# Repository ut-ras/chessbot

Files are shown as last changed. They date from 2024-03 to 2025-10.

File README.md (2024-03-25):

# ChessBot: Automated Chessboard

## Overview

ChessBot is an innovative project developed by the IEEE RAS - Demobots team. It is a CNC-inspired automated chessboard designed to enhance the experience of playing chess. Using an actuated electromagnet gantry system, ChessBot can move magnetized chess pieces across the board autonomously, allowing for a seamless game between two players or against a computer-controlled opponent. The project aims to merge the ancient game of chess with modern technology, providing a unique and interactive experience.

## Features

- **Automated Piece Movement**: Moves chess pieces using an electromagnet on a step-driven gantry system, controlled under the board.

- **Magnetized Chess Pieces**: Each piece is magnetized for precise and secure movement. Piece movements are detected via 3D magnetic sensors underneath each square.

- **Player vs. Computer Mode**: Play against an AI with adjustable difficulty settings.

- **Two-Player Online Mode**: Enjoy an enhanced tele-chess experience with automated piece movements that reflect your partner's movements from across the internet using Lichess

## Installation & Setup (WIP)

Make sure you have Python 3.6 or higher installed on your system. You can download it from the [official Python website](https://www.python.org/downloads/).

If on Windows use WSL for now, as the code is not tested on Windows.

1. Clone the repository to your local machine:

```bash
git clone https://github.com/ut-ras/chessbot.git 
```

2. Install the required Python packages:

```bash
cd chessbot
pip install -r requirements.txt
```
3. install stockfish and note what path it is installed to, you will need this for the python script. On Ubuntu or WSL you can do this with the following commands:

```bash
sudo apt-get install stockfish && which stockfish
```
The output of the `which stockfish` command will be the path to the stockfish binary. Copy that path, you will need this for the python script.

4. In the `python/bitboard_with_stockfish.py` file, change the `stockfish_path` variable to the path of the stockfish binary you found in the previous step.

5. Run the Python script:

```bash
python python/bitboard_with_stockfish.py
```

## Software

- [python/bitboard_with_stockfish.py](python/bitboard_with_stockfish.py) - This is the main file that runs the chess engine. It uses the python-chess library to interface with the Stockfish chess engine. The bitboard implementation is a custom implementation that uses 64-bit integers to represent the chessboard. Makes calls to functions in [python/display_output.py](python/display_output.py), animates the board for a 128x64 display, currently only makes the bitmap.

  - Bitboards are 64bit integer representations of the entire chessboard. 8x8 squares = 64 squares, so a digital for each individual square, that digit is 1 when a piece is on the corresponding square and 0 when a piece is absent from the square.
  - So far we arent using any "standard" bitboard implementations, as our situation is a tad unique. Most chess engines that utilize 12 bitboards, one for each piece type, ( [pawn + knight + bishop + rook + queen + king] * 2 teams = 12 piece types).
  - Here is a diagram of how each space on the chessboard is indexed in the bitboard, the number at each square is the digital that is either high or low depending on if a piece is there or not. For example, square `a4` is position `32`

     ``` 
       8 |  0  1  2  3  4  5  6  7
       7 |  8  9 10 11 12 13 14 15
       6 | 16 17 18 19 20 21 22 23
       5 | 24 25 26 27 28 29 30 31
       4 | 32 33 34 35 36 37 38 39
       3 | 40 41 42 43 44 45 46 47
       2 | 48 49 50 51 52 53 54 55
       1 | 56 57 58 59 60 61 62 63
          -------------------------
          a  b  c  d  e  f  g  h
      ```

## TODO
 - Assemble and test chessboard PCB's - each is an individual rank of the board that connect together.
-  Fill this section in with what we have left to do lol

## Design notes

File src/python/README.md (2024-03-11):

# Simple Chess Bitboard Implementation

This code provides a basic implementation of a chess game using a bitboard representation. It features classes for managing both a traditional 2D array-based board (`RealBoard`) and a 64-bit integer representation (`Bitboard`). The goal is to enable chess move input, update the bitboard accordingly, track changes to test for move legality, and interact with the Stockfish chess engine for move suggestions.

## Overview

- **RealBoard**: A class representing a chessboard using a 2D array. Black pieces are lowercase, while white pieces are uppercase. This class tracks the actual state of the game.
- **Bitboard**: Represents the chessboard as a 64-bit integer, where each bit corresponds to a board square, facilitating efficient move generation and board evaluation.
- **StockfishEngine**: A class for interfacing with the Stockfish chess engine, allowing the program to calculate optimal moves based on the current board state.

## Key Concepts

- **Square vs. Position**: In the context of this code, "square" refers to chessboard coordinates (e.g., a1, h8), while "position" refers to the corresponding index (0-63) in the bitboard representation.
- **Board Representation**: For easy reference, the board is indexed as follows:

```

8 |  0  1  2  3  4  5  6  7
7 |  8  9 10 11 12 13 14 15
6 | 16 17 18 19 20 21 22 23
5 | 24 25 26 27 28 29 30 31
4 | 32 33 34 35 36 37 38 39
3 | 40 41 42 43 44 45 46 47
2 | 48 49 50 51 52 53 54 55
1 | 56 57 58 59 60 61 62 63
\-------------------------
a  b  c  d  e  f  g  h

```

## Features

- **Board Initialization and Display**: Both `RealBoard` and `Bitboard` classes can set up a default chess board and print it in a human-readable format.
- **Move Handling**: Functions are provided for converting user input into board moves, updating the board state, and validating moves.
- **Chess Engine Integration**: The `StockfishEngine` class allows the program to communicate with Stockfish, providing move suggestions and evaluations based on the current game state.

## Usage

1. The game initializes the chessboard in both `RealBoard` and `Bitboard` formats.
2. The user is prompted to enter a move in a specific format (e.g., "e2e4").
3. The program validates the move, updates the board state, and then prints the new board configuration.
4. The Stockfish engine suggests a move based on the current board state, which is also executed and displayed.
5. The game loop continues, alternating between user input and engine suggestions.

## Dependencies

- Python 3
- A local installation of the Stockfish chess engine

## Setup

Ensure you have Python 3 installed and the Stockfish engine executable available on your system. Adjust the `path_to_stockfish` variable in the code to point to your Stockfish executable.

## Running the Program

Execute the script from the command line. The game will start, and you'll be prompted to enter moves in the specified format. Follow the on-screen instructions to play against the Stockfish engine.

## Note

This implementation is a simplified demonstration and may not cover all chess rules and scenarios (e.g., en passant, castling, piece promotions).

```

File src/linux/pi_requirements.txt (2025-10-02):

Adafruit-Blinka==8.39.0
adafruit-circuitpython-busdevice==5.2.6
adafruit-circuitpython-connectionmanager==1.0.1
adafruit-circuitpython-neopixel==6.3.11
adafruit-circuitpython-pixelbuf==2.0.4
adafruit-circuitpython-requests==3.2.3
adafruit-circuitpython-typing==1.10.3
Adafruit-PlatformDetect==3.62.0
Adafruit-PureIO==1.1.11
certifi==2024.2.2
charset-normalizer==3.3.2
colorzero==2.0
gpiozero==2.0.1
idna==3.7
paho-mqtt==2.1.0
pigpio==1.78
pyftdi==0.55.0
pyserial==3.5
pyusb==1.2.1
requests==2.31.0
RPi.GPIO==0.7.1
rpi_ws281x==5.0.0
smbus==1.1.post2
smbus2==0.4.3
sysv-ipc==1.1.0
typing_extensions==4.11.0
urllib3==1.26.0
board==1.0
chess==1.10.0
gpiozero==2.0.1
matplotlib==3.8.4
numpy==1.26.4
Pillow==11.1.0
Requests==2.31.0
smbus==1.1.post2

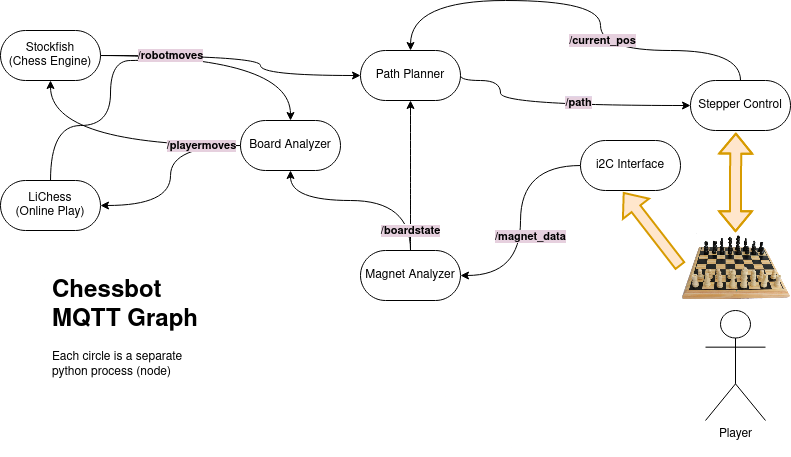
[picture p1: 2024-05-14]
src/display/HighLevelDiagram.drawio.png

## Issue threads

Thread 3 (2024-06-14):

magnetometer @ 0x35 does not work after second init

karmanyaahm, 2024-06-14:
probably some sort of conflict with the default address

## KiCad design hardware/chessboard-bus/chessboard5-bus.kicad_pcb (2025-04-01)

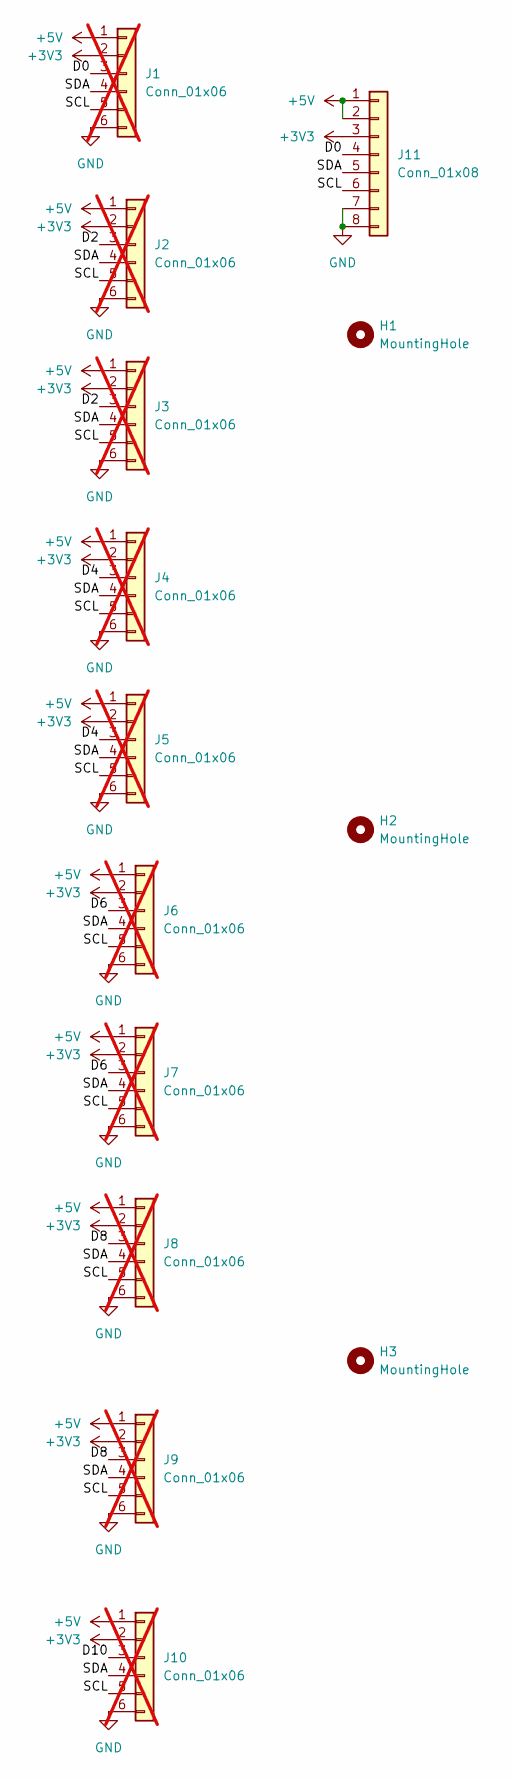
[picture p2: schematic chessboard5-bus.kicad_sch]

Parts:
H1, H2, H3: MountingHole; MountingHole_3.2mm_M3
J1, J2, J3, J4, J5, J6, J7, J8, J9, J10: Conn_01x06; PinHeader_2x03_P2.54mm_Vertical; not fitted
J11: Conn_01x08; JST_PH_S8B-PH-SM4-TB_1x08-1MP_P2.00mm_Horizontal

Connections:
+3V3: J1.2, J2.2, J3.2, J4.2, J5.2, J6.2, J7.2, J8.2, J9.2, J10.2, J11.3
+5V: J1.1, J2.1, J3.1, J4.1, J5.1, J6.1, J7.1, J8.1, J9.1, J10.1, J11.1, J11.2
/D0: J1.3, J11.4
/D2: J2.3, J3.3
/D4: J4.3, J5.3
/D6: J6.3, J7.3
/D8: J8.3, J9.3
/D10: J10.3
/SCL: J1.5, J2.5, J3.5, J4.5, J5.5, J6.5, J7.5, J8.5, J9.5, J10.5, J11.6
/SDA: J1.4, J2.4, J3.4, J4.4, J5.4, J6.4, J7.4, J8.4, J9.4, J10.4, J11.5
GND: J1.6, J2.6, J3.6, J4.6, J5.6, J6.6, J7.6, J8.6, J9.6, J10.6, J11.7, J11.8

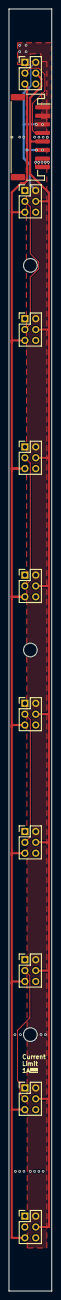
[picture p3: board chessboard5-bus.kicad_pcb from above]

Board: 2 copper layers, 10.0 x 300.0 mm, 14 parts (0 on the bottom side), 10 nets.

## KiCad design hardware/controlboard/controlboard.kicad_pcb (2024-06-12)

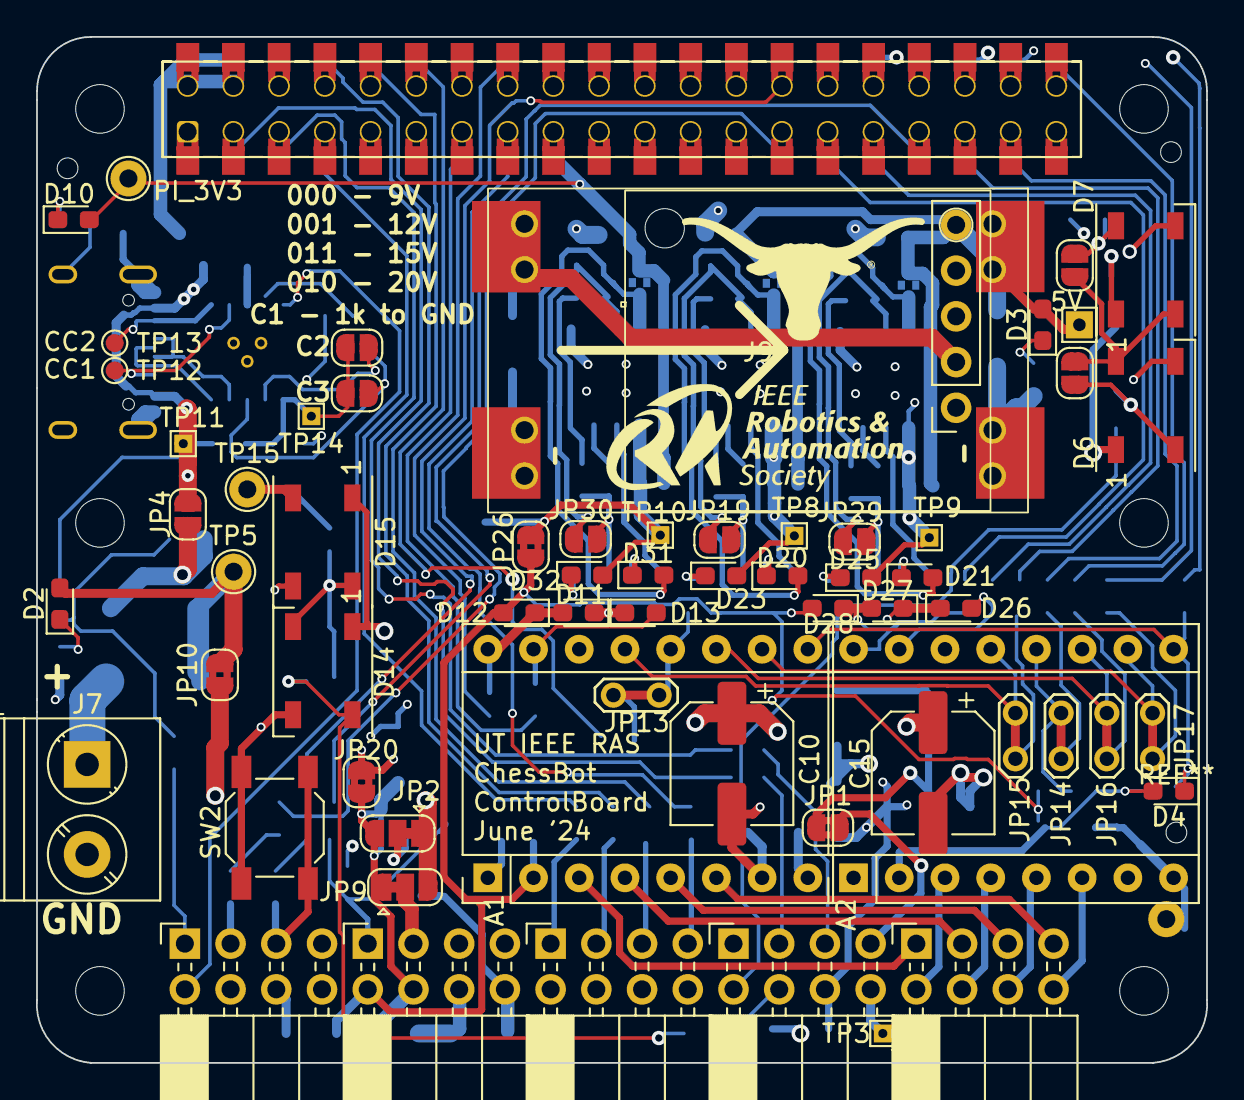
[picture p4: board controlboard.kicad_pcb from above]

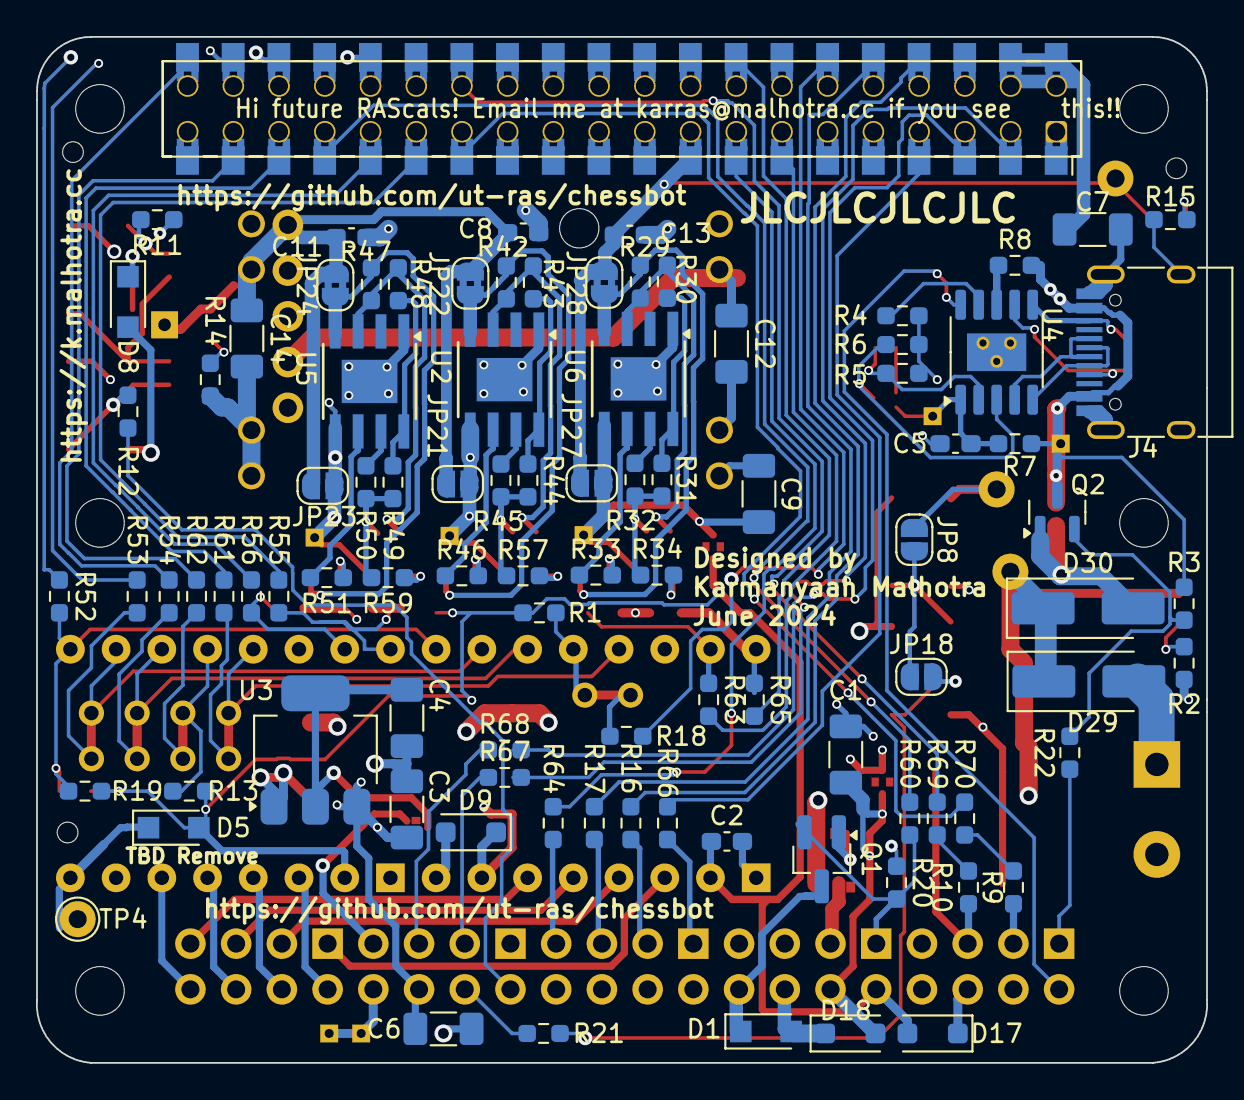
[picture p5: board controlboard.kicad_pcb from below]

Board: 4 copper layers, 65.0 x 57.0 mm, 166 parts (95 on the bottom side), 118 nets.

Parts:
A1: Pololu_Breakout_MP6500; Pololu_Breakout-16_15.2x20.3mm
A2: SilentStepStick TMC5160T; Pololu_Breakout-16_15.2x20.3mm
C1, C3, C4, C6, C7, C9, C12, C14: 22uF; C_1206_3216Metric_Pad1.33x1.80mm_HandSolder
C2, C8, C11, C13: 100n; C_0603_1608Metric_Pad1.08x0.95mm_HandSolder
C5: 1u; C_0603_1608Metric_Pad1.08x0.95mm_HandSolder
C10, C15: 100u; CP_Elec_6.3x5.4
D1, D5, D8: SM4007PL; Nexperia_CFP3_SOD-123W
D2, D3, D4, D10: Y; LED_0603_1608Metric_Pad1.05x0.95mm_HandSolder
D6, D7, D14, D15: WS2812B; LED_WS2812B_PLCC4_5.0x5.0mm_P3.2mm
D9: 20V+ D_TVS; D_SOD-123F
D11, D13, D23, D25, D26, D27, D32: G; LED_0603_1608Metric_Pad1.05x0.95mm_HandSolder
D12, D20, D21, D28, D31: R; LED_0603_1608Metric_Pad1.05x0.95mm_HandSolder
D17: 3V3V+ D_TVS; D_SOD-123F
D18: 6V+ D_TVS; D_SOD-123F
D29, D30: SS54; D_SMA_Handsoldering
J1, J3, J6: Conn_02x04_Counter_Clockwise; PinSocket_2x04_P2.54mm_Horizontal
J2: Conn_02x04_Row_Letter_Last; PinSocket_2x04_P2.54mm_Horizontal
J4: TYPE-C-31-M-12; USB_C_Receptacle_HRO_TYPE-C-31-M-12
J5: Conn_02x04_Row_Letter_First; PinSocket_2x04_P2.54mm_Horizontal
J7: Screw_Terminal_01x02; TerminalBlock_Phoenix_PT-1,5-2-5.0-H_1x02_P5.00mm_Horizontal
J9: mini560 voltage regulator; mini560
J11: Pololu Voltage Regulator; reg15d
J27: GPIO; Samtec_HLE-120-02-xxx-DV-BE-A_2x20_P2.54mm_Horizontal
JP1, JP10, JP20, JP22, JP24, JP26, JP28: SolderJumper_2_Bridged; SolderJumper-2_P1.3mm_Bridged2Bar_RoundedPad1.0x1.5mm
JP2, JP9: SolderJumper_3_Bridged12; SolderJumper-3_P1.3mm_Bridged12_RoundedPad1.0x1.5mm
JP4, JP8, JP11, JP12, JP18, JP19, JP29, JP30: SolderJumper_2_Open; SolderJumper-2_P1.3mm_Open_RoundedPad1.0x1.5mm
JP6, JP7: CFG3; SolderJumper-2_P1.3mm_Open_RoundedPad1.0x1.5mm
JP13, JP14, JP15, JP16, JP17: Jumper_2_Bridged; Bridged_TestPoint_2Pads_Pitch2.54mm_Drill0.8mm
JP21, JP23, JP27: Bypass; SolderJumper-2_P1.3mm_Open_RoundedPad1.0x1.5mm
MH1, MH2, MH3, MH3#2, MH4, MH4#2: MountingHole_2.7mm_M2.5
Q1: NMOS AO3400A; SOT-23_Handsoldering
Q2: PMOS AO3401A; SOT-23
R1, R3, R8, R13, R19, R20, R22, R43, R48: 10k; R_0603_1608Metric_Pad0.98x0.95mm_HandSolder
R2, R4, R5, R6, R7, R9, R10, R11, R12, R14, R15, R16, R17, R18, R21, R34, R52, R55, R56, R57, R59, R60, R62, R63, R64, R65, R66: 1k; R_0603_1608Metric_Pad0.98x0.95mm_HandSolder
R29: 82k; R_0603_1608Metric_Pad0.98x0.95mm_HandSolder
R30: 20k; R_0603_1608Metric_Pad0.98x0.95mm_HandSolder
R31, R44, R49: 47k; R_0603_1608Metric_Pad0.98x0.95mm_HandSolder
R32, R33, R46, R51: 3k; R_0603_1608Metric_Pad0.98x0.95mm_HandSolder
R42, R47: 150k; R_0603_1608Metric_Pad0.98x0.95mm_HandSolder
R45, R50: 470R; R_0603_1608Metric_Pad0.98x0.95mm_HandSolder
R53, R54, R61, R67, R68, R69, R70: 100; R_0603_1608Metric_Pad0.98x0.95mm_HandSolder
SW2: SW_Push TODO FP CHECK; SW_SPST_SKQG_WithStem
TP1, TP3, TP8, TP9, TP10, TP11, TP14: TestPoint; TestPoint_THTPad_1.0x1.0mm_Drill0.5mm
TP4, TP5, TP7, TP15: TestPoint; TestPoint_THTPad_D2.0mm_Drill1.0mm
TP6: TestPoint; TestPoint_THTPad_1.5x1.5mm_Drill0.7mm
TP12, TP13: TestPoint; TestPoint_Pad_D1.0mm
U2, U5, U6: TPS25963x; TI_SO-PowerPAD-8
U3: AMS1117-3.3; SOT-223-3_TabPin2
U4: CH224K; SSOP-10-1EP_3.9x4.9mm_P1mm_EP2.1x3.3mm

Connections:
/CH_5V: C3.1, C6.1, C15.1, D6.1 (VDD), D8.2 (A), D14.1 (VDD), D15.1 (VDD), D23.2 (A), J3.6, J6.4, JP20.2 (B), JP21.1 (A), TP8.1, U2.5 (OUT), U3.3 (VI)
/CH_SCL: J3.5, R68.1
/CH_SDA: J3.3, R67.1
/CNC/(CS/I1)1: A1.12 (I1), JP13.2 (B), R1.2
/CNC/(CS/I1)2: A2.12 (CS), JP14.2 (B), R13.2
/CNC/SCK/MS2: A1.11 (MS2), A2.11 (SCK), JP16.2 (B)
/CNC/SDI/MS1: A1.10 (MS1), A2.10 (SDI), JP17.2 (B)
/CNC/SDO/I2: A1.13 (I2), A2.13 (SDO), JP15.2 (B)
/CNC/SERVO_VIN: C1.1, D18.2 (A2), J5.4, JP2.1 (A), JP9.3 (B), JP20.1 (A)
/CNC/VIO: A1.2 (~FLT), A2.2 (VIO), C2.1, D4.2 (A), D5.2 (A), D12.2 (A), D17.2 (A2), D28.2 (A), J5.2, JP26.1 (A), R1.1, R13.1, R19.1
/CNC/VMOT: A1.8 (VMOT), A2.8 (VMOT), C10.1, D5.1 (K), D9.2 (A2), JP2.3 (B), JP9.1 (A), JP10.1 (A), TP4.1
/ChessBoard/3V3: C4.1, JP1.2 (B), U3.2 (VO)
/ChessBoard/LED_IN: D15.2 (DOUT), JP8.1 (A), TP15.1
/ChessBoard/LED_IN_REAL: D14.4 (DIN), JP18.2 (B), R21.2
/ChessBoard/LED_OUT: J3.2, R12.1
/DIR1: A1.16 (DIR), D11.2 (A), D12.1 (K), R65.1
/DIR2: A2.16 (DIR), D27.2 (A), D28.1 (K), R55.1
/ENBL: A1.9 (~ENABLE), A2.9 (~ENABLE), D4.1 (K), R19.2, R52.2
/ID_SCL: J6.5, R10.2, SW2.1
/ID_SDA: J6.3, R9.1
/LED_DATA: D7.4 (DIN), JP11.2 (B), R11.2
/LIM_SW1: J2.1, R66.1
/LIM_SW2: J2.3, R16.2
/LIM_SW3: J2.5, R17.2
/LIM_SW4: J2.7, R64.1
/MAG_PWM: J5.1, Q1.2 (G), R20.2, R60.1
/MOT_CS1: JP13.1 (A), R18.2
/MOT_CS2: JP14.1 (A), R62.1
/MOT_SCK: JP16.1 (A), R54.2
/MOT_SDI: JP17.1 (A), R53.2
/MOT_SDO: JP15.1 (A), R61.1
/PI_3V3: C13.1, D10.2 (A), J27.17, JP27.2 (B), JP28.2 (B), TP7.1
/PI_5V: C7.1, D25.2 (A), J27.2, J27.4, JP23.1 (A), TP9.1, U5.5 (OUT)
/Power/CH_VDD: C5.1, JP6.1 (A), JP7.1 (A), R7.1, TP14.1, U4.1 (VDD)
/Power/CNC_VIO: C9.1, D32.2 (A), JP26.2 (B), JP27.1 (A), TP10.1, U6.5 (OUT)
/Power/PWR_SW_A: J6.2, U4.10 (PG)
/Power/PWR_SW_B: J6.1, R22.1
/Power/UNLIM_5V: C8.1, C11.1, C14.1, D3.2 (A), J9.1, J11.5, JP21.2 (B), JP22.2 (B), JP23.2 (B), JP24.2 (B), TP6.1
/Power/UNLIM_VIN: C12.1, D2.2 (A), D29.1 (K), D30.1 (K), J6.8, J9.3, J11.2, JP10.2 (B), TP5.1
/Power/VBUS: J4.A4 (VBUS), J4.A9 (VBUS), J4.B4 (VBUS), J4.B9 (VBUS), JP4.1 (A), Q2.3 (S), R3.1, R7.2, R8.2, TP11.1
/STEP1: A1.15 (STEP), D13.2 (A), R63.1
/STEP2: A2.15 (STEP), D26.2 (A), R56.1
GND: A1.1 (GND), A1.7 (GND), A2.1 (GND), A2.7 (GND), C1.2, C2.2, C3.2, C4.2, C5.2, C6.2, C7.2, C8.2, C9.2, C10.2, C11.2, C12.2, C13.2, C14.2, C15.2, D1.2 (A), D6.3 (VSS), D7.3 (VSS), D9.1 (A1), D11.1 (K), D13.1 (K), D14.3 (VSS), D15.3 (VSS), D17.1 (A1), D18.1 (A1), D26.1 (K), D27.1 (K), J2.2, J2.4, J2.6, J2.8, J3.1, J4.A1 (GND), J4.A12 (GND), J4.B1 (GND), J4.B12 (GND), J4.S1 (SHIELD), J5.5, J5.6, J5.7, J6.6, J6.7, J7.2, J9.2, J9.4, J11.3, J11.4, J27.6, J27.9, J27.14, J27.20, J27.25, J27.30, J27.34, J27.39, JP19.1 (A), JP29.1 (A), JP30.1 (A), R2.1, R4.1, R5.1, R6.1, R14.1, R15.1, R20.1, R31.2, R32.2, R34.1, R44.2, R45.2, R49.2, R50.2, R57.1, R59.1, SW2.2, U2.1 (GND), U2.9 (GND), U3.1 (GND), U4.11 (GND), U5.1 (GND), U5.9 (GND), U6.1 (GND), U6.9 (GND)
unnamed: A1.4 (1A), J1.3
unnamed: A1.3 (1B), J1.1
unnamed: A1.5 (2A), J1.5
unnamed: A1.6 (2B), J1.7
unnamed: A2.4 (1A), J1.4
unnamed: A2.3 (1B), J1.2
unnamed: A2.5 (2A), J1.6
unnamed: A2.6 (2B), J1.8
unnamed: D1.1 (K), J5.8, Q1.3 (S)
unnamed: D2.1 (K), R2.2
unnamed: D3.1 (K), R14.2
unnamed: D6.4 (DIN), D7.2 (DOUT), JP11.1 (A), JP12.2 (B)
unnamed: D6.2 (DOUT), JP12.1 (A), R12.2
unnamed: D7.1 (VDD), D8.1 (K)
unnamed: D10.1 (K), R15.2
unnamed: D14.2 (DOUT), D15.4 (DIN), JP8.2 (B), JP18.1 (A)
unnamed: D20.2 (A), JP22.1 (A), R42.1, U2.4 (IN)
unnamed: D20.1 (K), R46.2
unnamed: D21.2 (A), JP24.1 (A), R47.1, U5.4 (IN)
unnamed: D21.1 (K), R51.2
unnamed: D23.1 (K), R57.2
unnamed: D25.1 (K), R59.2
unnamed: D29.2 (A), J7.1
unnamed: D30.2 (A), JP4.2 (B), Q2.1 (D)
unnamed: D31.2 (A), JP28.1 (A), R29.1, U6.4 (IN)
unnamed: D31.1 (K), R33.2
unnamed: D32.1 (K), R34.2
unnamed: J3.4, R21.1
unnamed: J3.7, JP1.1 (A)
unnamed: J3.8, TP1.1, TP3.1
unnamed: J4.A5 (CC1), TP12.1, U4.7 (CC1)
unnamed: J4.B5 (CC2), TP13.1, U4.6 (CC2)
unnamed: J5.3, JP2.2 (C)
unnamed: J27.3, R67.2
unnamed: J27.5, R68.2
unnamed: J27.7, R66.2
unnamed: J27.8, R16.1
unnamed: J27.10, R17.1
unnamed: J27.12, R18.1
unnamed: J27.13, R63.2
unnamed: J27.15, R64.2
unnamed: J27.16, R65.2
unnamed: J27.27, R70.2
unnamed: J27.28, R69.1
unnamed: J27.29, R55.2
unnamed: J27.31, R56.2
unnamed: J27.32, R11.1
unnamed: J27.33, R60.2
unnamed: J27.35, R61.2
unnamed: J27.36, R52.1
unnamed: J27.37, R62.2
unnamed: J27.38, R53.1
unnamed: J27.40, R54.1
unnamed: JP6.2 (B), R5.2, U4.2 (CFG2)
unnamed: JP7.2 (B), R6.2, U4.3 (CFG3)
unnamed: JP9.2 (C), Q1.1 (D)
unnamed: JP19.2 (B), R42.2, R43.1, U2.3 (EN/UVLO)
unnamed: JP29.2 (B), R47.2, R48.1, U5.3 (EN/UVLO)
unnamed: JP30.2 (B), R29.2, R30.1, U6.3 (EN/UVLO)
unnamed: Q2.2 (G), R3.2, R22.2
unnamed: R10.1, R69.2
unnamed: R9.2, R70.1
unnamed: R45.1, U2.7 (ILim)
unnamed: R43.2, R44.1, U2.8 (OVLO)
unnamed: R46.1, U2.6 (~FLT)
unnamed: R4.2, U4.9 (CFG1)
unnamed: J4.A7 (D-), J4.B7 (D-), U4.5 (DM)
unnamed: J4.A6 (D+), J4.B6 (D+), U4.4 (DP)
unnamed: R8.1, U4.8 (VBUS)
unnamed: R50.1, U5.7 (ILim)
unnamed: R48.2, R49.1, U5.8 (OVLO)
unnamed: R51.1, U5.6 (~FLT)
unnamed: R32.1, U6.7 (ILim)
unnamed: R30.2, R31.1, U6.8 (OVLO)
unnamed: R33.1, U6.6 (~FLT)

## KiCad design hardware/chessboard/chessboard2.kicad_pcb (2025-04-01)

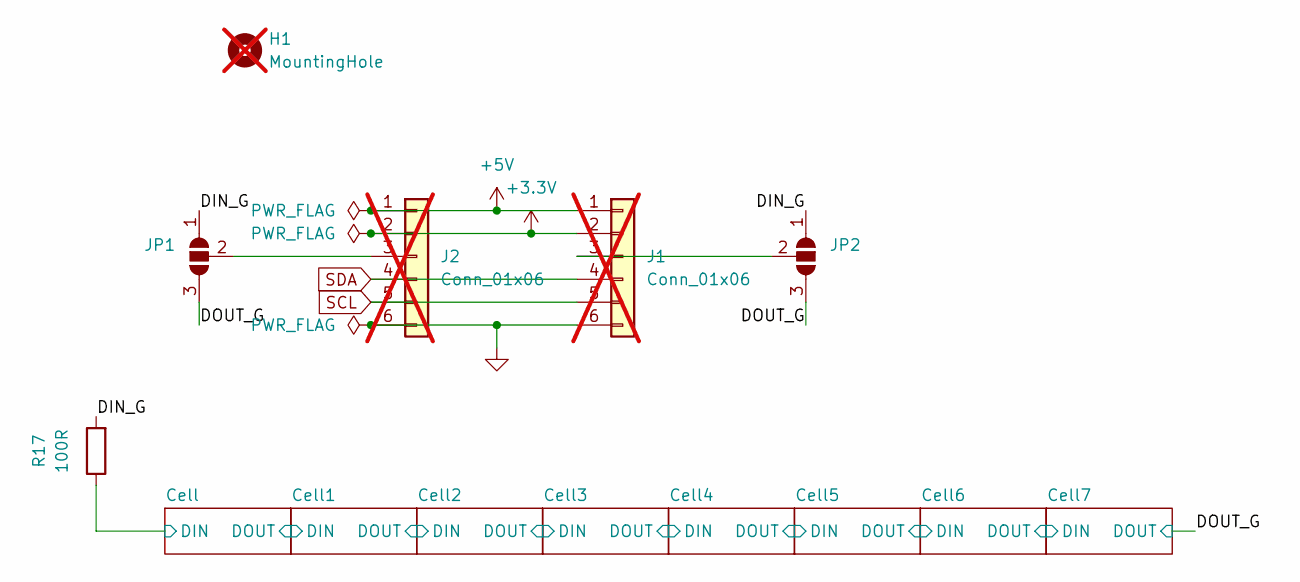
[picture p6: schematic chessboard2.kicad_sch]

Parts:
H1: MountingHole; MountingHole_3.2mm_M3; not fitted
J1, J2: Conn_01x06; PinHeader_2x03_P2.54mm_Vertical; not fitted
JP1, JP2: SolderJumper_3_Open; SolderJumper-3_P1.3mm_Open_RoundedPad1.0x1.5mm
R17: 100R; R_0603_1608Metric_Pad0.98x0.95mm_HandSolder

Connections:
+3.3V: J1.2, J2.2; also elsewhere on the board
+5V: J1.1, J2.1; also elsewhere on the board
/Cell/DIN: R17.1; also elsewhere on the board
/DIN_G: JP1.1 (A), JP2.1 (A), R17.2
/DOUT_G: JP1.3 (B), JP2.3 (B); also elsewhere on the board
GND: J1.6, J2.6; also elsewhere on the board
unnamed: J1.3, JP2.2 (C)
unnamed: J2.3, JP1.2 (C)
SCL: J1.5, J2.5; also elsewhere on the board
SDA: J1.4, J2.4; also elsewhere on the board

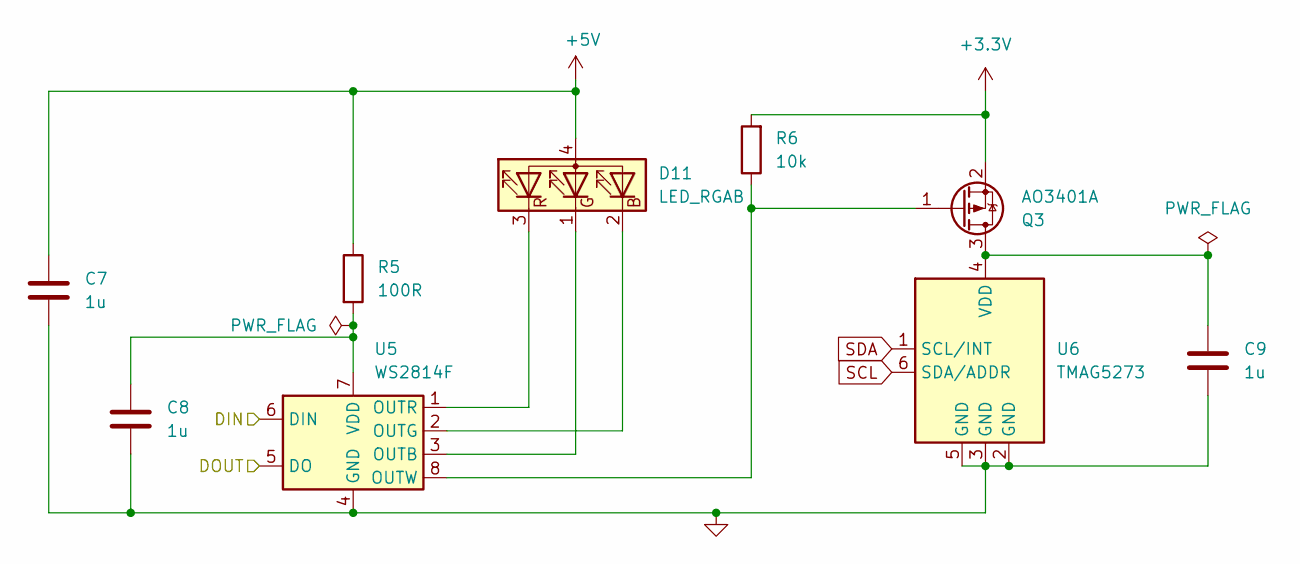
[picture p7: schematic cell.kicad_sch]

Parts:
C7, C8, C9: 1u; C_0603_1608Metric_Pad1.08x0.95mm_HandSolder
D11: LED_RGAB; LED_RGB_Wuerth-PLCC4_3.2x2.8mm_150141M173100
Q3: AO3401A; SOT-23_Handsoldering
R5: 100R; R_0603_1608Metric_Pad0.98x0.95mm_HandSolder
R6: 10k; R_0603_1608Metric_Pad0.98x0.95mm_HandSolder
U5: WS2814F; FSOP-8
U6: TMAG5273; SOT-23-6_Handsoldering

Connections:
+3.3V: Q3.2 (S), R6.2; also elsewhere on the board
+5V: C7.1, D11.4 (A), R5.1; also elsewhere on the board
/Cell1/DOUT: U5.6 (DIN); also elsewhere on the board
/Cell2/DOUT: U5.5 (DO); also elsewhere on the board
GND: C7.2, C8.2, C9.2, U5.4 (GND), U6.2 (GND), U6.3 (GND), U6.5 (GND); also elsewhere on the board
unnamed: D11.2 (BK), U5.2 (OUTG)
unnamed: D11.1 (GK), U5.3 (OUTB)
unnamed: D11.3 (RK), U5.1 (OUTR)
unnamed: C9.1, Q3.3 (D), U6.4 (VDD)
unnamed: Q3.1 (G), R6.1, U5.8 (OUTW)
unnamed: C8.1, R5.2, U5.7 (VDD)
SCL: U6.6 (SDA/ADDR); also elsewhere on the board
SDA: U6.1 (SCL/INT); also elsewhere on the board

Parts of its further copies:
C1, C2, C3, C4, C5, C6, C10, C11, C12, C13, C14, C15, C16, C17, C18, C19, C20, C21, C22, C23, C24: 1u; C_0603_1608Metric_Pad1.08x0.95mm_HandSolder
D9, D10, D12, D13, D14, D15, D16: LED_RGAB; LED_RGB_Wuerth-PLCC4_3.2x2.8mm_150141M173100
Q1, Q2, Q4, Q5, Q6, Q7, Q8: AO3401A; SOT-23_Handsoldering
R1, R3, R7, R9, R11, R13, R15: 100R; R_0603_1608Metric_Pad0.98x0.95mm_HandSolder
R2, R4, R8, R10, R12, R14, R16: 10k; R_0603_1608Metric_Pad0.98x0.95mm_HandSolder
U1, U3, U7, U9, U11, U13, U15: WS2814F; FSOP-8
U2, U4, U8, U10, U12, U14, U16: TMAG5273; SOT-23-6_Handsoldering

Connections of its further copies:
+3.3V: Q1.2 (S), Q2.2 (S), Q4.2 (S), Q5.2 (S), Q6.2 (S), Q7.2 (S), Q8.2 (S), R2.2, R4.2, R8.2, R10.2, R12.2, R14.2, R16.2; also elsewhere on the board
+5V: C1.1, C4.1, C10.1, C13.1, C16.1, C19.1, C22.1, D9.4 (A), D10.4 (A), D12.4 (A), D13.4 (A), D14.4 (A), D15.4 (A), D16.4 (A), R1.1, R3.1, R7.1, R9.1, R11.1, R13.1, R15.1; also elsewhere on the board
/Cell1/DOUT: U3.5 (DO); also elsewhere on the board
/Cell2/DOUT: U7.6 (DIN); also elsewhere on the board
/Cell3/DOUT: U7.5 (DO), U9.6 (DIN)
/Cell4/DOUT: U9.5 (DO), U11.6 (DIN)
/Cell5/DOUT: U11.5 (DO), U13.6 (DIN)
/Cell6/DOUT: U13.5 (DO), U15.6 (DIN)
/Cell/DIN: U1.6 (DIN); also elsewhere on the board
/Cell/DOUT: U1.5 (DO), U3.6 (DIN)
/DOUT_G: U15.5 (DO); also elsewhere on the board
GND: C1.2, C2.2, C3.2, C4.2, C5.2, C6.2, C10.2, C11.2, C12.2, C13.2, C14.2, C15.2, C16.2, C17.2, C18.2, C19.2, C20.2, C21.2, C22.2, C23.2, C24.2, U1.4 (GND), U2.2 (GND), U2.3 (GND), U2.5 (GND), U3.4 (GND), U4.2 (GND), U4.3 (GND), U4.5 (GND), U7.4 (GND), U8.2 (GND), U8.3 (GND), U8.5 (GND), U9.4 (GND), U10.2 (GND), U10.3 (GND), U10.5 (GND), U11.4 (GND), U12.2 (GND), U12.3 (GND), U12.5 (GND), U13.4 (GND), U14.2 (GND), U14.3 (GND), U14.5 (GND), U15.4 (GND), U16.2 (GND), U16.3 (GND), U16.5 (GND); also elsewhere on the board
unnamed: D9.2 (BK), U1.2 (OUTG)
unnamed: D9.1 (GK), U1.3 (OUTB)
unnamed: D9.3 (RK), U1.1 (OUTR)
unnamed: D10.2 (BK), U3.2 (OUTG)
unnamed: D10.1 (GK), U3.3 (OUTB)
unnamed: D10.3 (RK), U3.1 (OUTR)
unnamed: D12.2 (BK), U7.2 (OUTG)
unnamed: D12.1 (GK), U7.3 (OUTB)
unnamed: D12.3 (RK), U7.1 (OUTR)
unnamed: D13.2 (BK), U9.2 (OUTG)
unnamed: D13.1 (GK), U9.3 (OUTB)
unnamed: D13.3 (RK), U9.1 (OUTR)
unnamed: D14.2 (BK), U11.2 (OUTG)
unnamed: D14.1 (GK), U11.3 (OUTB)
unnamed: D14.3 (RK), U11.1 (OUTR)
unnamed: D15.2 (BK), U13.2 (OUTG)
unnamed: D15.1 (GK), U13.3 (OUTB)
unnamed: D15.3 (RK), U13.1 (OUTR)
unnamed: D16.2 (BK), U15.2 (OUTG)
unnamed: D16.1 (GK), U15.3 (OUTB)
unnamed: D16.3 (RK), U15.1 (OUTR)
unnamed: C3.1, Q1.3 (D), U2.4 (VDD)
unnamed: Q1.1 (G), R2.1, U1.8 (OUTW)
unnamed: C6.1, Q2.3 (D), U4.4 (VDD)
unnamed: Q2.1 (G), R4.1, U3.8 (OUTW)
unnamed: C12.1, Q4.3 (D), U8.4 (VDD)
unnamed: Q4.1 (G), R8.1, U7.8 (OUTW)
unnamed: C15.1, Q5.3 (D), U10.4 (VDD)
unnamed: Q5.1 (G), R10.1, U9.8 (OUTW)
unnamed: C18.1, Q6.3 (D), U12.4 (VDD)
unnamed: Q6.1 (G), R12.1, U11.8 (OUTW)
unnamed: C21.1, Q7.3 (D), U14.4 (VDD)
unnamed: Q7.1 (G), R14.1, U13.8 (OUTW)
unnamed: C24.1, Q8.3 (D), U16.4 (VDD)
unnamed: Q8.1 (G), R16.1, U15.8 (OUTW)
unnamed: C2.1, R1.2, U1.7 (VDD)
unnamed: C5.1, R3.2, U3.7 (VDD)
unnamed: C11.1, R7.2, U7.7 (VDD)
unnamed: C14.1, R9.2, U9.7 (VDD)
unnamed: C17.1, R11.2, U11.7 (VDD)
unnamed: C20.1, R13.2, U13.7 (VDD)
unnamed: C23.1, R15.2, U15.7 (VDD)
SCL: U2.6 (SDA/ADDR), U4.6 (SDA/ADDR), U8.6 (SDA/ADDR), U10.6 (SDA/ADDR), U12.6 (SDA/ADDR), U14.6 (SDA/ADDR), U16.6 (SDA/ADDR); also elsewhere on the board
SDA: U2.1 (SCL/INT), U4.1 (SCL/INT), U8.1 (SCL/INT), U10.1 (SCL/INT), U12.1 (SCL/INT), U14.1 (SCL/INT), U16.1 (SCL/INT); also elsewhere on the board

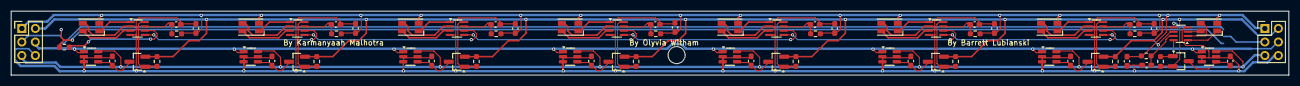
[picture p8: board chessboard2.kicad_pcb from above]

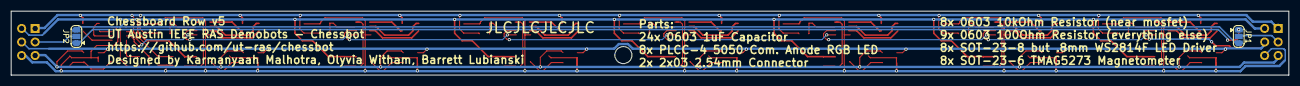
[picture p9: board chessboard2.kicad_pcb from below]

Board: 2 copper layers, 240.0 x 12.0 mm, 78 parts (2 on the bottom side), 65 nets.

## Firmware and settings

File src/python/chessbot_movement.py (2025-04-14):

import RPi.GPIO as GPIO

from time import sleep
from gpiozero import Servo, Device
from gpiozero.pins.pigpio import PiGPIOFactory
import paho.mqtt.client as mqtt

# Set up GPIO pin factory to use PiGPIO for hardware PWM
Device.pin_factory = PiGPIOFactory()

# Define pins and setup
x_step_pin = 27  
x_dir_pin = 17   
y_step_pin = 6  
y_dir_pin = 5    
x_limit_switch_pin = 6  
y_limit_switch_pin = 13  
servo_pin = 14  # For servo motor 
electromagnet_pin = 18  # For electromagnet 

# Setup GPIO mode
GPIO.setmode(GPIO.BCM)
GPIO.setup([x_step_pin, x_dir_pin, y_step_pin, y_dir_pin, electromagnet_pin], GPIO.OUT)
#GPIO.setup([x_limit_switch_pin, y_limit_switch_pin], GPIO.IN, pull_up_down=GPIO.PUD_UP)

# Setup servo motor
servo = Servo(servo_pin)

# Initialize electromagnet state
GPIO.output(electromagnet_pin, GPIO.LOW)

# Constants
steps_per_mm = 12  # Placeholder value previously 20
board_origin_offset_mm = 0  # Distance from home to A1 square corner, Placeholder value
square_size_mm = 30 #previously 50
current_x, current_y = 0,0

def home_axis(axis):
    if axis == 'x':
        GPIO.output(x_dir_pin, GPIO.LOW)  # Assume LOW moves towards home
        GPIO.output(y_dir_pin, GPIO.HIGH)  # Assume LOW moves towards home
        a = 200 * steps_per_mm
        while a > 0:
            a-=1
            GPIO.output(x_step_pin, GPIO.HIGH)
            GPIO.output(y_step_pin, GPIO.LOW)
            sleep(0.001)  # Short pulse duration
            GPIO.output(x_step_pin, GPIO.LOW)
            GPIO.output(y_step_pin, GPIO.HIGH)
            sleep(0.001)  # Step interval
        current_x = 0
    elif axis == 'y':
        a = 200 * steps_per_mm
        GPIO.output(y_dir_pin, GPIO.LOW)  # Assume LOW moves towards home
        GPIO.output(x_dir_pin, GPIO.LOW)  # Assume LOW moves towards home
        while a > 0:
            a-=1
            GPIO.output(y_step_pin, GPIO.HIGH)
            GPIO.output(x_step_pin, GPIO.LOW)
            sleep(0.001)
            GPIO.output(y_step_pin, GPIO.LOW)
            GPIO.output(x_step_pin, GPIO.HIGH)
            sleep(0.001)
        current_y = 0

def home_axes(): # Call this function to home both axes
    home_axis('x')
    home_axis('y')


def square_to_coordinates(square): # Converts chess square to coordinates (e.g., "a1" -> (0, 0))
    # Converts chess square to coordinates (e.g., "a1" -> (0, 0))
    column = ord(square[0]) - ord('a')
    row = int(square[1]) - 1
    return (column * square_size_mm, row * square_size_mm)

def move_to_square(square):  # Move to a square on the board
    global current_x, current_y
    target_x, target_y = square_to_coordinates(square)
    
    steps_to_move_x = (target_x - current_x) * steps_per_mm
    steps_to_move_y = (target_y - current_y) * steps_per_mm
    
    print("at: ", current_x, " ", current_y, " going to: ", target_x, " ", target_y)
    
    # Move X Axis
    GPIO.output(x_dir_pin, GPIO.HIGH if steps_to_move_x > 0 else GPIO.LOW)
    GPIO.output(y_dir_pin, not (GPIO.HIGH if steps_to_move_x > 0 else GPIO.LOW))
    for _ in range(abs(steps_to_move_x)):
        GPIO.output(y_step_pin, GPIO.HIGH)
        GPIO.output(x_step_pin, GPIO.LOW)
        sleep(0.001)
        GPIO.output(y_step_pin, GPIO.LOW)
        GPIO.output(x_step_pin, GPIO.HIGH)
        sleep(0.001)

    
    # Move Y Axis
    GPIO.output(x_dir_pin, GPIO.HIGH if steps_to_move_y > 0 else GPIO.LOW)
    GPIO.output(y_dir_pin, (GPIO.HIGH if steps_to_move_y > 0 else GPIO.LOW))
    for _ in range(abs(steps_to_move_y)):
        GPIO.output(y_step_pin, GPIO.HIGH)
        GPIO.output(x_step_pin, GPIO.LOW)
        sleep(0.001)
        GPIO.output(y_step_pin, GPIO.LOW)
        GPIO.output(x_step_pin, GPIO.HIGH)
        sleep(0.001)

    # Update current position
    current_x = target_x
    current_y = target_y


# Function to pick up or release a piece
def manipulate_piece_em(engage):
    if engage:
        GPIO.output(electromagnet_pin, GPIO.HIGH)
    else:
        GPIO.output(electromagnet_pin, GPIO.LOW)

def manipulate_piece_servo(engage):
    if engage:
        servo.min()
    else:
        servo.max()

# Function to perform a move in UCI format
def perform_uci_move(uci_move):
    from_square, to_square = uci_move[:2], uci_move[2:]
    move_to_square(from_square)  # Move above the piece to pick up
    manipulate_piece_em(True)  # Pick up the piece
    move_to_square(to_square)  # Move to the destination square
    manipulate_piece_em(False)  # Release the piece

def perform_castling(uci_castling):
    # Move the king, then the rook
    if uci_castling == "e1g1":
        move_to_square("e1")
        manipulate_piece_servo(True)
        move_to_square("g1")
        manipulate_piece_servo(False)
        move_to_square("h1")
        manipulate_piece_servo(True)
        move_to_square("f1")
        manipulate_piece_servo(False)
    elif uci_castling == "e1c1":
        move_to_square("e1")
        manipulate_piece_servo(True)
        move_to_square("c1")
        manipulate_piece_servo(False)
        move_to_square("a1")
        manipulate_piece_servo(True)
        move_to_square("d1")
        manipulate_piece_servo(False)
    elif uci_castling == "e8g8":
        move_to_square("e8")
        manipulate_piece_servo(True)
        move_to_square("g8")
        manipulate_piece_servo(False)
        move_to_square("h8")
        manipulate_piece_servo(True)
        move_to_square("f8")
        manipulate_piece_servo(False)
    elif uci_castling == "e8c8":
        move_to_square("e8")
        manipulate_piece_servo(True)
        move_to_square("c8")
        manipulate_piece_servo(False)
        move_to_square("a8")
        manipulate_piece_servo(True)
        move_to_square("d8")
        manipulate_piece_servo(False)

def on_message(client, userdata, message):
    # userdata is the structure we choose to provide, here it's a list()
    if (message.topic == "/moves"):
        mes = message.payload.strip().decode()
        if not mes: return
        print(mes)

        perform_uci_move(mes)
        
    # We only want to process 10 messages
   

def on_connect(client, userdata, flags, reason_code, properties):
    if reason_code.is_failure:
        print(f"Failed to connect: {reason_code}. loop_forever() will retry connection")
    else:
        print(f"Successfully connected")
        # we should always subscribe from on_connect callback to be sure
        # our subscribed is persisted across reconnections.
        client.subscribe("$SYS/#")
        client.subscribe("/moves")


mqttc = mqtt.Client(mqtt.CallbackAPIVersion.VERSION2)
mqttc.on_connect = on_connect
mqttc.on_message = on_message
mqttc.connect("localhost")

if __name__ == "__main__":
    try:
        home_axes()
        mqttc.loop_forever()
        #perform_uci_move("a1b2")

        choice = ""
        while choice != "q":
            choice = input("Enter move: ")
            perform_uci_move(choice.strip())
        #move_to_square("b2")
    except KeyboardInterrupt:
        pass
    finally:
        GPIO.cleanup()

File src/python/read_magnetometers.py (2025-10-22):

import smbus
from time import sleep, time
from i2cdev import I2C

import paho.mqtt.client as mqtt
import struct

bus_number = 1


COLUMNS = 8
ROWS = 8

DEBUG = False
PCA_OFFSET = 0  # 0 for normal use, 0-7 for debugging a single board that is not yet daisy chained
PCA_OG_ADDR = 0x70
PCA_ADDR = PCA_OG_ADDR + PCA_OFFSET
PCA_TO_PHYSICAL_WIRING_ORDER = [0,1,2,3,4,5,6,7]

current_power_state = [0x00] * 8 

#ban_addrs = banned_addresses_that_are_being_mean_to_me = []

# these addresses are tmaga1s (+- 40mT) whereas all the others are tmaga2s (+= 133mT)
tmag1s = [0x36]

#ban_adr = [((i - 0x20) // COLUMNS, PCA_TO_PHYSICAL_WIRING_ORDER.index((i-0x20) % COLUMNS)) for i in banned_addresses_that_are_being_mean_to_me]


mqttc = mqtt.Client(mqtt.CallbackAPIVersion.VERSION2)

def power_on(upto):
    upto += 1
    a=b''

    a += b'\xff' * (upto // 8)
    if len(a) < 8: a += bytes([0xff >> (8-(upto % 8))])
    if len(a) < 8: a += b'\x00' * ((8- upto // 8  - 1) )

    c = b''
    for i in range(64):
        c+= b'\x01\xff\x01' if i < upto else b'\x00\x00\x00'

    mqttc.publish("/magpower", a, retain=True)
    mqttc.publish("/led", c)




def power_on_single(addr):
   
    global current_power_state

    index = addr - 0x20      # 0–63 index
    row = index // 8
    col = index % 8

    # set that bit on
    current_power_state[row] |= (1 << col)

    # Publish updated power state
    a = bytes(current_power_state)
    mqttc.publish("/magpower", a, retain=True)

    #print(f"Turned ON TMAG at addr {hex(addr)} (row {row}, col {col})")






def power_off():
    a=b'\x00'*8
    mqttc.publish("/magpower", a, retain=True)


def power_off_single(addr):
    index = addr - 0x20          # map address to 0–63 index
    row = index // 8
    col = index % 8

    power_state = [0xFF] * 8     # start with all on
    power_state[row] &= ~(1 << col)

    a = bytes(power_state)
    mqttc.publish("/magpower", a, retain=True)

   # print(f"Turned off TMAG at addr {hex(addr)} (row {row}, col {col})")



#class PCAArray:
#    def __init__(self):
#        self.bus = smbus.SMBus(bus_number)
#    def softDisableAll(self):
#        for i in range(0, ROWS):
#            try: 
#                pigpio.i2c_write_byte(self.pcas[i], 0)
#                #if .read_byte(PCA_ADDR + i) != 0: print("ERR WRITING")
#                # TODO
#            except: pass
#     
#    # chip from 0 to 7
#    def enableOnly(self, chip, line):
#        self.softDisableAll()
#        # enable
#        self.bus.write_byte(PCA_ADDR + chip, 1 << line)
#    def unsafeEnableRow(self, chip):
#        on = 0xff
#        for chp, sq in ban_adr:
#            if chip == chp:
#                on &= ~(1 << sq)
#        #print(bin(on), chip)
#        self.bus.write_byte(PCA_ADDR + chip, on)
#    def unsafeDisableRow(self, chip):
#        self.bus.write_byte(PCA_ADDR + chip, 0x00)
#    def enableAll(self):
#        for i in range(0, ROWS):
#            try:
#                self.bus.write_byte(PCA_ADDR + i, enabled_cells[i])
#            except: pass
#switches = PCAArray()

tmagcache = {}
class TMAG5273:
    def __init__(self, addr):
        self.bus = smbus.SMBus(bus_number)
        self.device_address = addr
        if addr in tmag1s:
            self.RANGE = 80
        else:
            self.RANGE = 266

    @classmethod
    def init(self, new_addr, old_addr = 0x78):
        conf = self.config()
        conf[0xC] |= new_addr << 1
        smbus.SMBus(bus_number).write_i2c_block_data(old_addr, 0, conf)

    @classmethod
    def config(self):
        thing = [0 for _ in range(0, 0xD)]
        thing[0] |= 0 << 7; #NO TODO IT DOESN"T LIKE IT # Enable CRC
        # ignore magtempcompensation
        thing[0] |= 0x5 << 2; # 32x averaging = 400 samples / sec
        thing[0] |= 0x1; # 16 bit, 1-byte fast read command

        # cfg 2
        # ignore threshold stuff
        thing[1] |= 1 << 4; # low noise mode
        # leave glitch filter default
        # leave trigger mode default through i2c
        thing[1] |= 0x2; # continuous measure mode, TODO try wake up and sleep mode, 0x3

        # sensor cfg 1
        thing[2] |= 0x7 << 4; # enable xyz channels
        # leave w&s timing to the default of 1ms

        # sensor cfg 2
        # ignore threshold, angle calculation magic
        thing[3] |= 0x1 << 1; # XY axes range is the bigger one (40->80 or 133->266)
        thing[3] |= 0x1;      # z axis is bigger one

        # ignore threshold cfg registers
        # thing 4 to 6 = 0

        # enable temp acquisition cuz why not
        # no need for temp threshold
        thing[7] = 1; # 0th bit, enable data acquisition of temp
                      # interrupt pin
                      # most functions are disable by default
        thing[8] = 1; # 0th bit, Mask interrupt (it's connected to ground, so ignore the pin)

        # ignore mag gain/angle stuff registers
        # thing 9, A, B = 0

        # C 1..7 = I2C address will be put in by parent
        thing[0xC] = 1; # enable updating the address at the end of this transaction
        return thing


    def read_magnetism(self):
        # Command to start a measurement and read the data
        #self.bus.write_byte(self.device_address, 0x10)
        # Wait for the measurement to complete (adjust the delay according to the datasheet)
        #sleep(0.1)
        # Read 6 bytes of data (X, Y, Z magnetic field values)

        #if self.device_address in ban_addrs:
        #    return 10,10,-32
        if self.device_address not in tmagcache:
            tmagcache[self.device_address] = I2C(self.device_address, bus_number)
        i2c = tmagcache[self.device_address]
        #data = self.bus.read_i2c_block_data(self.device_address, 0x12, 6)
        data1 = list(bytearray(i2c.read(8)))         # read 1 byte
        data1 = data1[2:]
        #i2c.close()                 # close connection

        #print(data == data1, data, data1)
        #print(len(data))
        #print(data)
        data = data1
        x = twos_complement_int(data[1], data[0]) * self.RANGE  / 2**15
        y = twos_complement_int(data[3], data[2]) * self.RANGE  / 2**15
        z = twos_complement_int(data[5], data[4]) * self.RANGE  / 2**15
        return x, y, z


# CHATGPT AF
def twos_complement_int(LSB, MSB):
    # Concatenate the two bytes into a single 16-bit value
    value = (MSB << 8) | LSB
    
    # If the highest bit (bit 15) is set, the number is negative
    if value & 0x8000:
        # Convert to signed integer by subtracting 65536
        return -((~value & 0xFFFF) + 1)
    else:
        return value
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

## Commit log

2024-01-20 lay out chess board sensors + leds
    [ChessBoard.kicad_sch, chessbot.kicad_sch, row.kicad_sch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]
2024-01-21 add some power logic, split chessboard and control board
    [ChessBoard.kicad_sch, chessboard.kicad_pcb, chessboard.kicad_sch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]
2024-02-01 new single row board
    [ChessBoard.kicad_sch, chessboard.kicad_pcb, chessboard.kicad_sch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]
2024-02-06 make it pretty
    [chessboard.kicad_pcb, chessboard.kicad_sch, row.kicad_sch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]
2024-02-06 ready to buy
    [chessboard.kicad_pcb, row.kicad_sch]
2024-02-06 ok good now forreal
    [chessboard.kicad_pcb]
2024-02-08 Works, only testing first move against default board so far
2024-02-08 cleaned up slightly, need to fix validity check as well
    [bitboard_move_analysis_test.py]
2024-02-15 define API and do some sensor stuff
2024-02-15 implement sensorarray and magvals
2024-02-20 dumdum i2c
2024-03-17 Added stockfish diffficulty selection, fixed some check detection issues, still have castling issues
    [bitboard_with_stockfish.py, display_output.py]
2024-03-18 added some starting code for the stepper movement integration
2024-05-11 led write from mqtt
2024-05-11 demo with magnets lighting up the LEDs near them
2024-05-12 negligible magnetometer stuff
2024-05-14 updates to controlboard
    [Power.kicad_sch, USB.kicad_sch, controlboard.kicad_pcb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]
2024-05-16 fixed path to work with rook
    [path_planner.py]
2024-05-20 Control Board major progress
    [Power.kicad_sch, chessboard.kicad_sch, cnc.kicad_sch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]
2024-05-20 remove USB
    [USB.kicad_sch, controlboard.kicad_sch]
2024-05-21 boardstate tester added and fixed path
    [path_planner.py]
2024-05-21 just added file and folder
    [just_long_term_steady_state_nothing_really_changes.csv, knight_g1h3.csv, no_movement_just_a_king_and_queen_e3_and_d1.csv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]
2024-05-23 board state work in progress
2024-05-25 bad naming on my part
    [pawn_take_knight_g2h3_alt_positioning.csv]
2024-05-25 more progress on controlboard pcb
    [Power.kicad_sch, chessboard.kicad_sch, cnc.kicad_sch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]
2024-05-25 huge changes for magnetometer reader performance
2024-05-25 make i2c faster
2024-05-25 better values in magnet_to_led visualizer
2024-05-25 Fix magnet recordings to 64 squares (dummy data) and rename
    [just_long_term_steady_state_nothing_really_changes.csv, just_long_term_steady_state_nothing_really_changes_3of8.csv, knight_g1h3.csv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]
2024-05-25 switch to 2 val /path
2024-05-25 dum bug in magnet_to_led merge
    [magnet_to_led.py]
2024-05-27 ControlBoard Schematic nearly done
    [Power.kicad_sch, chessboard.kicad_sch, cnc.kicad_sch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]
2024-05-28 disable prints
2024-05-28 schematic improvements
    [Power.kicad_sch, chessboard.kicad_sch, cnc.kicad_sch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]
2024-05-28 improve pinout
    [Power.kicad_sch, chessboard.kicad_sch, controlboard.kicad_sch]
2024-05-28 erc should be good now
    [Power.kicad_sch, chessboard.kicad_sch, cnc.kicad_sch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]
2024-05-29 pcb layout work
    [Power.kicad_sch, cnc.kicad_sch, controlboard.kicad_pcb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]
2024-06-01 yay its all connected
    [Power.kicad_sch, chessboard.kicad_sch, cnc.kicad_sch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]
2024-06-03 controlboard: fix critical mosfet errors
    [Power.kicad_sch, chessboard.kicad_sch, cnc.kicad_sch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]
2024-06-03 remove production file
    [controlboard.csv]
2024-06-04 nice silkscreen stuff
    [controlboard.kicad_pcb, controlboard.kicad_sch]
2024-06-04 update pcb easter egg
    [controlboard.kicad_pcb]
2024-06-05 vectors on tester, boardstate
2024-06-12 controlboard finalized and ordered!!!
    [Power.kicad_sch, chessboard.kicad_sch, cnc.kicad_sch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]
2024-06-14 significantly improve led output perfomance
2024-06-14 change led behavior slightly
2024-06-14 magnetometer: remove disabled squares; account for TMAGA1 chip in one square
2024-07-08 python/stepper: more dynamic fast timings
2024-07-08 magnet_to_bitboard_boardstate.py added
2024-07-08 python/path_planner: flip rows properly
    [path_planner.py]
2024-07-09 Very basic player move and stockfish response (no captures yet)
    new file: python/.gitignore
    modified: python/bitboard.py
    modified: python/bitboard_with_stockfish.py
    new file: python/board_analyzer.py
    deleted: python/magnet_to_bitboard_boardstate.py
    new file: python/realboard.py
2024-11-12 We fixed the tester i.e. work-er
    [Cell.kicad_sch, bufferedtester.kicad_sch, freerouting.dsn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]
2024-11-19 Control board changes
    Made a few control board changes (green checks on discord)
    [Power.kicad_sch, chessboard.kicad_sch, cnc.kicad_sch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]
2024-12-03 update slightly
    [chessboard2.kicad_sch]
2025-01-03 fix up schematic for chessboard5
    [cell.kicad_sch, chessboard2.kicad_pcb, chessboard2.kicad_sch]
2025-01-04 pcb progress 2
    [chessboard2.kicad_pcb]
2025-01-04 finished chessboard v5!!!
    [cell.kicad_sch, chessboard2.kicad_pcb, chessboard2.kicad_sch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]
2025-01-09 fix chessboard5 for ordering;
    [cell.kicad_sch, chessboard2.kicad_pcb, chessboard2.kicad_sch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]
2025-03-05 arduino tester
2025-04-09 rwbg leds
2025-04-09 leds fixed
2025-04-13 make stepper wokr
2025-04-13 make led work
2025-04-13 fixed magnetometer ordering issues
    [led_mqtt.py, magnet_to_led.py, read_magnetometers.py]
2025-04-14 stepper directions not flipped anymore yay
    [drv8825.py]
2025-10-01 clean up repo
    [Cell.kicad_sch, Power.kicad_sch, bufferedtester.kicad_sch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]
2025-10-02 Revert controlboard to June 12th 2024
    [Power.kicad_sch, chessboard.kicad_sch, cnc.kicad_sch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]
